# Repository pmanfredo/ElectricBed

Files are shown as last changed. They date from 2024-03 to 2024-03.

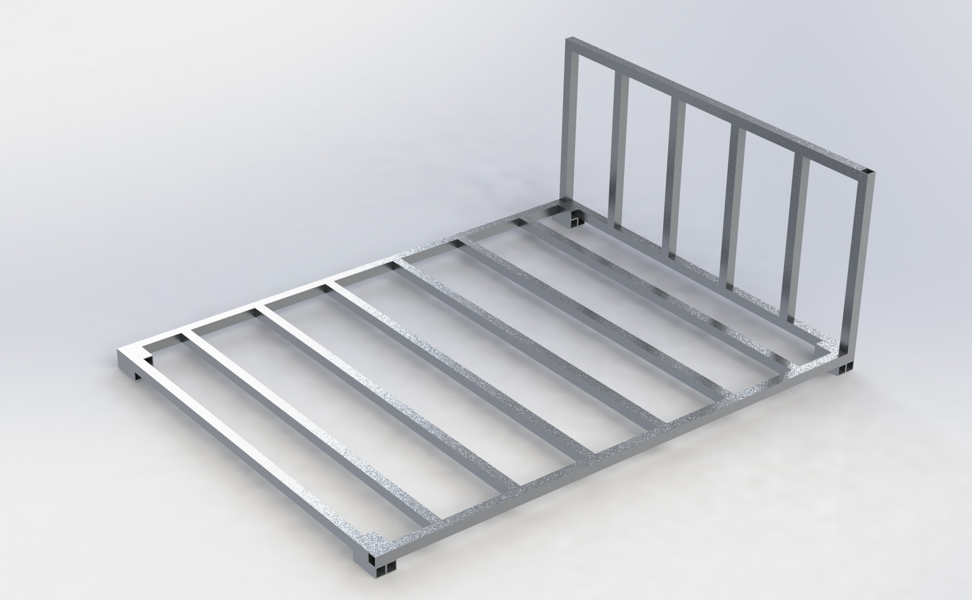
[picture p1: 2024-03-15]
Other Files/Renderings/electric bed render v1.JPG

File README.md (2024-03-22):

# ElectricBed: Motorized Queen-Sized Bed Project

Welcome to the `ElectricBed` project! This comprehensive guide is designed to assist you in creating a low-speed, electrically powered vehicle, uniquely constructed as a queen-sized bed that can carry two people. It's remotely controlled, featuring advanced functionalities such as telemetry feedback, dynamic control systems, and LED lighting, all managed by an Arduino Mega 2560.

**This project is an ongoing endeavor, with new features and enhancements being added and completed over time.**

## Overview

The ElectricBed project transforms the concept of mobility and rest into a single, innovative design. Equipped with dual Electronic Speed Controllers (ESCs), input from a FlySky FS-i6X transmitter, LED lighting effects, and a motion sensor for enhanced driving stability, this project invites hobbyists and developers to explore the fusion of comfort and technology.

### Key Features

- Dynamic speed and turn control for smooth maneuverability.
- Telemetry feedback for battery monitoring and RPM-based adjustments, ensuring safe and efficient operation.
- Customizable LED lighting for aesthetic appeal and visibility.
- Motion detection for improved stability and traction control, enhancing passenger comfort.
- Auxiliary controls via relays for headlights, parking lights, turn signals, horn, reverse light, and volume control.
- Comprehensive safety features such as an emergency stop mechanism and a 2-step kill switch.

### Required Hardware

- Arduino Mega 2560 for central control.
- Two Electronic Speed Controllers (ESCs) for motor management.
- FlySky FS-i6X remote control transmitter and receiver for remote operation.
- HiLetgo X9C104 Digital Potentiometer Module for volume control.
- Adafruit NeoPixel LED Strip for customizable lighting.
- MPU6050 Accelerometer and Gyro Sensor for motion detection and stability control.
- Relay module(s) for controlling auxiliary features like headlights, parking lights, turn signals, horn, and reverse light.
- Adequate power sources for the Arduino, ESCs, LEDs, and any other peripherals.

### Wiring Instructions

1. **ESC Connections**: Connect the ESCs to the Arduino's `Serial1` and `Serial2` ports (TX1/RX1 for ESC 1, TX2/RX2 for ESC 2) for motor control.
2. **iBus Receiver**: Connect to `Serial3` (TX3/RX3) on the Arduino to receive input from the FlySky transmitter.
3. **LED Strip**: Attach to pin `6` on the Arduino for lighting effects.
4. **MPU6050 Sensor**: Use the Arduino's I2C ports (SDA and SCL) for connection.
5. **Digital Potentiometer**: Connect the U/D, INC, and CS pins of the X9C104 to digital pins `10`, `11`, and `12` respectively on the Arduino.
7. **Power Connections**: Ensure all components are appropriately powered according to their specifications.

## Relay Wiring Instructions

The project utilizes a series of relays to control various components such as turn signals, headlights, horn, and more. Below are the detailed wiring instructions for each relay connected to the Arduino:

- **Relays**: The project uses relays for controlling different functionalities. Each relay is controlled by a specific digital pin on the Arduino Mega 2560.

### Relay Connections

- **Relay 1 (Headlights)**: Connect to digital pin 2.
- **Relay 2 (Parking Lights)**: Connect to digital pin 3.
- **Relay 3 (Horn)**: Connect to digital pin 4.
- **Relay 4 (Turn Signals - Left)**: Connect to digital pin 5.
- **Relay 5 (Turn Signals - Right)**: Connect to digital pin 6.
- **Relay 6 (Reverse Light)**: Connect to digital pin 7.
- **Relay 7 (Volume Control/Mute for Sound System)**: Connect to digital pin 8.
- **Relay 8 (LED Scene Control)**: Connect to digital pin 9.

### Program Overview

The provided code orchestrates various functions:

- Initialization of serial ports, ESCs, iBus receiver, relays, LED strip, digital potentiometer, and I2C devices in the `setup()`.
- Continuous monitoring and processing of control inputs, telemetry data, safety checks, and volume adjustments in the `loop()`.
- Customizable control modes (RPM, Duty, Current) for varying operational preferences.
- Relay control for auxiliary functions and LED color customization for personalization and visibility.

### Volume Control Setup

- At startup, the digital potentiometer is reset to its minimum value to establish a reference point.
- Volume adjustments are made relative to this reference point, allowing for precise control over the audio output level.
- The current position of the digital potentiometer's wiper is tracked to facilitate efficient and accurate adjustments.

### Getting Started

1. Assemble the bed frame and attach the motors, ensuring all hardware is securely mounted.
2. Wire the components according to the instructions, taking care to correctly connect all electronic elements.
3. Upload the program to your Arduino Mega 2560.
4. Configure the FlySky transmitter to communicate with the receiver.
5. Conduct initial tests in a safe, controlled environment to ensure stability and operational safety.

### Customization and Safety

Customize acceleration rates, turn sensitivity, LED behavior, and more to enhance the driving experience and ensure passenger comfort. Prioritize safety by securely fastening all components and conducting thorough testing before use.

Enjoy building and operating your ElectricBed, a unique blend of technology, comfort, and mobility!

## Upcoming Features

We're continuously working to enhance the ElectricBed experience with innovative features and improvements. Here are some of the exciting updates you can look forward to as we get them completed:

### Sound System with Remote Volume Control

Enjoy an immersive audio experience with a fully integrated sound system. Future updates will include the ability to control the volume directly from your FlySky FS-i6X remote, allowing for seamless adjustments without the need to stop or reach for a separate controller. Whether you're looking to set the mood with some background music or amp up the energy with your favorite tracks, having control at your fingertips will enhance your ElectricBed experience.

### Electric Bed App for Monitoring and Security Enhancements

Stay connected with your ElectricBed through our upcoming dedicated app. This application will not only allow you to monitor key vehicle metrics in real-time, such as battery levels, speed, and system diagnostics, but it will also introduce new layers of security and convenience:

- **Remote Monitoring**: Check on your ElectricBed's status, ensuring it's always ready for your next adventure.
- **Security Alerts**: Receive instant notifications for unauthorized movements or tampering, offering peace of mind when you're away from your vehicle *when it is on*.
- **Future Updates**: The app will serve as a platform for rolling out future features and enhancements, keeping your ElectricBed at the cutting edge of technology.

Stay tuned for these updates and more as we continue to innovate and expand the capabilities of the ElectricBed project. 

**If you have any features you would like to see added, please make a pull request or add to our discussion!**

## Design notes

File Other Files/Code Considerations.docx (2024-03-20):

# ### 1. **Error Handling and Safety Features:**

~~- **Fail-Safe~~ ~~Mechanism:*~~~~* Ensure there's a fail-safe mechanism in case the signal from the~~ ~~FlySky~~ ~~remote is lost. This could involve setting the motors to a neutral or stopped state if no signal is received for a predefined period.~~

- **Signal Validation:** Implement checks to ensure that the signals received from the remote are within expected ranges before acting on them, to prevent erratic behavior due to signal interference or corruption.

# ### 2. **Refinement in Speed and Turn Calculations:**

~~- **Smooth~~ ~~Acceleration:*~~~~* Consider implementing a smoother acceleration curve to avoid sudden starts and stops, which could be achieved through software by gradually adjusting the speed values towards the target speed.~~

- **Advanced Turning Logic:** For more intuitive control, especially at varying speeds, you might want to adjust the turning logic based on the current speed. At high speeds, smaller adjustments to turning might be preferable to maintain stability.

# ### 3. **Telemetry and Feedback:**

~~- **Use of Telemetry~~ ~~Data:*~~~~* If your ESCs support telemetry, you can use this data for battery monitoring, RPM feedback, and possibly for implementing features like traction control or even a simple form of stability control by adjusting power to the motors based on their actual RPM.~~

- **Feedback to Operator:** Consider sending critical telemetry data back to the operator through the remote's display if supported, or via an auxiliary display attached to the remote. This could include battery level, signal strength, or error codes.

# ### 4. **Motor Control Enhancements:**

~~- **Differential~~ ~~Steering:*~~~~* If your vehicle's design allows, differential steering (adjusting the speed of each side's motors independently for turning) can offer more precise control, especially at lower speeds or for in-place turns.~~

~~- **Dynamic ESC~~ ~~Configuration:*~~~~* Some ESCs allow dynamic configuration of parameters such as acceleration curves, braking strength, and reverse functionality. Adjusting these settings programmatically based on the vehicle's speed, direction, or operator input can enhance driving characteristics.~~

# ### 5. **Software Architecture:**

~~- **~~~~Modularity:*~~~~* Keep your code modular by separating functionality (e.g., motor control, signal processing, telemetry) into different functions or classes. This approach improves readability and makes it easier to maintain and extend your code.~~

~~- **Real-Time~~ ~~Considerations:*~~~~* Given the real-time nature of remote control, ensure your loop runs efficiently to minimize latency. Avoid or minimize the use of `~~~~delay(~~~~)`, and consider non-blocking alternatives for any task that might introduce lag.~~

# ### 6. **Debugging and Configuration Tools:**

- **Serial Debugging:** Utilize serial output for debugging purposes, providing insights into the system's state, received commands, and any errors or warnings.

- **Configuration Parameters:** Implement a mechanism (via remote control inputs, serial commands, or even a small set of buttons and an LCD on the vehicle) to adjust configuration parameters on the fly, such as maximum speed, sensitivity to control inputs, and fail-safe settings.

# ### 7. **Power Management:**

- **Power Supply Monitoring:** Continuously monitor the power supply to ensure the motors and ESCs are not drawing too much current, which could lead to voltage drops and potential brown-out conditions for the control electronics.

- **Efficient Power Use:** Optimize the power usage based on the telemetry data and the vehicle's operational state. For example, reducing power to the motors when the battery voltage drops below a certain threshold to extend run time.

# ### 8. **Documentation and Comments:**

- **Code Comments:** Ensure your code is well-commented, explaining the purpose of functions and the logic behind critical sections of your code. This practice is invaluable for maintenance and future modifications.

- **External Documentation:** Create external documentation for your project, including schematics, a wiring diagram, and a user manual. This is especially helpful if the project is complex or intended for use by others.

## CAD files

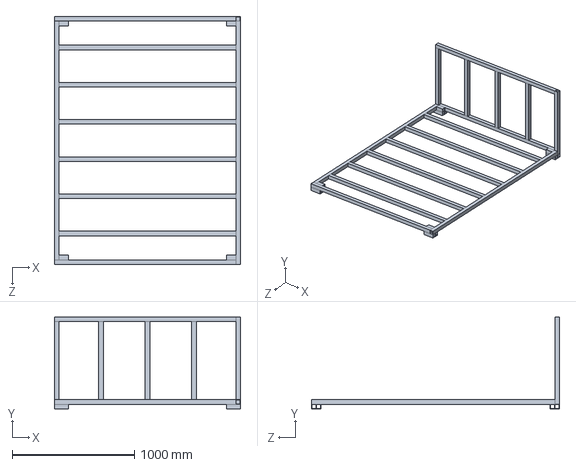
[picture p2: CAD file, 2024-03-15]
Other Files/Electric Bed Assembly.SLDASM
1524.0 x 752.5 x 2032.0 mm

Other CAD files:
Other Files/Bed Frame.SLDPRT
Other Files/Electric Bed Drawing.SLDDRW

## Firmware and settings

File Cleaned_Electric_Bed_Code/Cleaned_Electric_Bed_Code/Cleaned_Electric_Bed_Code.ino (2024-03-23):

#include <IBusBM.h>
#include <VescUart.h>
#include <Adafruit_NeoPixel.h>
#include "I2Cdev.h"
#include "MPU6050.h"
#if I2CDEV_IMPLEMENTATION == I2CDEV_ARDUINO_WIRE
    #include "Wire.h"
#endif

VescUart UART1; // VescUart object for commanding the ESC's
VescUart UART2; // VescUart object for commanding the ESC's
IBusBM IBus;    // IBus object for receiving signals from transmitter/receiver

unsigned long lastSignalTime = 0;         // Tracks the last time the signal was confirmed
const unsigned long signalTimeout = 1000; // Signal timeout in milliseconds
uint16_t lastCntRec = 0;                  // Last received count for detecting signal loss

// Control variables
int currentSpeed = 0, targetSpeed = 0, currentTurn = 0, targetTurn = 0;
int accelRate = 50, turnRate = 100; // Rate of change for speed and turn

// Telemetry variables
float batteryVoltage1 = 0.0, batteryVoltage2 = 0.0;
const float voltageWarningThreshold = 33.0;  // Threshold for 10S battery

bool movementEnabled = true; // Global variable to track movement enable state
bool reverse = false;

enum ControlMode { MODE_RPM, MODE_DUTY, MODE_CURRENT };
ControlMode controlMode = MODE_RPM; // Choose control mode: MODE_RPM, MODE_DUTY, or MODE_CURRENT

// ibus Channel Assignments
#define RJoyX 0
#define RJoyY 1
#define LJoyY 2
#define LJoyX 3
#define LPot 4
#define RPot 5
#define SWA 6
#define SWB 7
#define SWC 8
#define SWD 9
#define ON 1000
#define OFF 2000
#define MID 1500

bool startup = true;
bool dangerousTemp = false;
bool dangerousCurrent = false;
bool dangerousDuty = false;

// Temperature thresholds (degrees Celsius)
const float MOSFET_SAFE_TEMP = 80.0; // Maximum safe temperature for the ESC's MOSFETs
const float MOTOR_SAFE_TEMP = 80.0;  // Maximum safe temperature for the motor

// Current limits (Amps)
const float MOTOR_CURRENT_LIMIT = 50.0; // Maximum safe current for the motor

// Duty cycle limit (percentage)
const float DUTY_CYCLE_LIMIT = 95.0; // Maximum safe duty cycle percentage

// Define relay channels to Arduino pin numbers
const int relay1 = 2;
const int relay2 = 3;
const int relay3 = 4;
const int relay4 = 5;
const int relay5 = 6;
const int relay6 = 7;
const int relay7 = 8;
const int relay8 = 9;

// For tracking left joystick x-axis double-tap
unsigned long leftJoystickFirstHitTime = 0;
const unsigned long doubleTapMaxInterval = 500; // Max interval in ms for double-tap detection
bool leftJoystickInRangeLastTime = false;
int leftJoystickHitCount = 0;

const unsigned long hornDuration = 500; // Duration of the horn beep in milliseconds

// Define the pin that the LED strip is connected to
#define LED_PIN 6

// Define the number of LEDs in the strip
#define LED_COUNT 600

unsigned long previousMillis = 0; // will store last time LED was updated
const long interval = 0; // interval at which to blink (milliseconds)
unsigned int i = 0;

// Create an Adafruit_NeoPixel object
Adafruit_NeoPixel strip(LED_COUNT, LED_PIN, NEO_GRB + NEO_KHZ800);

MPU6050 accelgyro;
const int quickTurnThreshold = 100; // Example threshold, adjust based on testing

// Digipot control pins
const int pinUD = 10; // Up/Down pin
const int pinINC = 11; // Increment pin
const int pinCS = 12; // Chip Select pin

int currentWiperPosition = 0; // Current wiper position, starting at 0 (minimum)

// Setup function initializes the serial communication ports and prepares the system for operation.
void setup(){
    initializeSerial();
    setupESCs();
    IBus.begin(Serial3);
    waitForReceiver();
    //initializeRelays();
    initializeLEDStrip();
    //initializeI2CDevices();
}

// Main loop function checks for signal loss and processes control inputs if signal is present.
void loop(){
  //serialInput();
  //printChannelValues();
  if (IBus.cnt_rec != lastCntRec)
  {                            // Checks if new iBus messages have been received since the last loop iteration.
    updateTelemetry();         // Updates telemetry data from the ESCs for features like battery monitoring.
    processControlInputs();    // Reads control inputs from the receiver and adjusts motor speeds accordingly.
    lastCntRec = IBus.cnt_rec; // Updates the last iBus message count for the next loop iteration.
    lastSignalTime = millis(); // Updates the last signal time to the current time.
  }
  //delay(2000);
}

// Function to initialize the ESCs (Electronic Speed Controllers) by setting their respective serial ports.
void setupESCs(){
  Serial.println("Initializing ESCs..."); // Log message indicating the start of ESC initialization
  UART1.setSerialPort(&Serial1);          // Assigns Serial1 to UART1, linking the ESC to the first serial port
  UART2.setSerialPort(&Serial2);          // Assigns Serial2 to UART2, linking the second ESC to another serial port
  Serial.println("ESCs Initialized.");    // Log message indicating the ESCs have been successfully initialized
}

// Function to wait for the receiver to start sending data. This ensures the program doesn't proceed without a signal.
void waitForReceiver(){
  Serial.println("Waiting for receiver..."); // Log message indicating the program is waiting for receiver data
  while (IBus.cnt_rec == 0)
    delay(100);                          // Waits in a loop, delaying 100ms at a time until data is received from the receiver
  lastCntRec = IBus.cnt_rec;             // Stores the count of received messages for later comparison
  lastSignalTime = millis();             // Stores the current time as the last time a signal was received
  Serial.println("Receiver connected."); // Log message indicating a connection to the receiver has been established
}

void initializeSerial() {
    Serial.begin(9600);
    Serial1.begin(115200);
    Serial2.begin(115200);
    Serial3.begin(115200);
}

void initializeRelays() {
    const int relays[] = {relay1, relay2, relay3, relay4, relay5, relay6, relay7, relay8};
    for (int relay : relays) {
        pinMode(relay, OUTPUT);
        digitalWrite(relay, HIGH); // Assuming HIGH means OFF
    }
}

void initializeLEDStrip() {
    strip.begin();
    strip.show(); // Initialize all pixels to 'off'
}

void initializeI2CDevices() {
    Wire.begin();
    Serial.println("Initializing I2C devices...");
    accelgyro.initialize();
    Serial.println(accelgyro.testConnection() ? "MPU6050 connection successful" : "MPU6050 connection failed");
}

void setupDigipot() {
  pinMode(pinUD, OUTPUT);
  pinMode(pinINC, OUTPUT);
  pinMode(pinCS, OUTPUT);

  digitalWrite(pinCS, HIGH); // Deselect the device by default

  resetDigipotToMinimum();
}

void resetDigipotToMinimum() {
    // Select the digipot
    digitalWrite(pinCS, LOW);

    // Set to decrease wiper position
    digitalWrite(pinUD, LOW);
    for (int i = 0; i < 100; i++) { // Assuming 100 steps for the digipot
        // Pulse the INC pin
        digitalWrite(pinINC, HIGH);
        delay(1); // Short delay for the signal to register
        digitalWrite(pinINC, LOW);
        delay(1);
    }

    // Deselect the digipot
    digitalWrite(pinCS, HIGH);
}

void processControlInputs() {
  readInputs();
  checkTurnSignals();
  checkHornControl();
  checkHeadlights();
  checkHazardLights();
  controlVolumeAndMute();
  controlLEDScenes();

  // Applies smooth adjustments to speed and turn to avoid abrupt changes
  smoothAdjustments();
  
  //Turn system OFF or set current to 0 if input is 1000
  if (targetSpeed <= 1000) {
      UART1.setCurrent(0);
      UART1.setCurrent(0,101);
      UART2.setCurrent(0);
      UART2.setCurrent(0,101);
      //Serial.println("System turned off - Current set to 0.");
      currentSpeed = 1000;
      return;
  }

  // Depending on the control mode, map targetSpeed to the respective range and apply control
  switch (controlMode) {
      case MODE_RPM:
          // Map targetSpeed (1001-2000) to RPM range (0-7000), considering 1000 as OFF
          int rpmValue = map(currentSpeed, 1001, 2000, 1000, 7000);

          if (dangerousTemp || dangerousCurrent || dangerousDuty){
            rpmValue = rpmValue / 2;
          }

          if(reverse){
            rpmValue = -rpmValue;
          }
          applyControlRPM(rpmValue);
          break;
      case MODE_DUTY:
          // Map targetSpeed (1001-2000) to duty cycle range (0-80%)
          float dutyCycle = map(targetSpeed, 1001, 2000, 0, 80);

          if (dangerousTemp || dangerousCurrent || dangerousDuty){
            dutyCycle = dutyCycle / 2;
          }

          if(reverse){
            dutyCycle = -dutyCycle;
          }
          applyControlDuty(dutyCycle);
          break;
      case MODE_CURRENT:
          // Map targetSpeed (1001-2000) to current range (0-40A)
          float current = map(targetSpeed, 1001, 2000, 0, 40);

          if (dangerousTemp || dangerousCurrent || dangerousDuty){
            current = current / 2;
          }

          if(reverse){
            current = -current;
          }
          applyControlCurrent(current);
          break;
  }
}

void checkTurnSignals(){
  // Handling Left Joystick X-Axis for Turn Signals
  int leftJoystickX = IBus.readChannel(LJoyX);
  unsigned long currentMillis = millis();

  // Reset hit count if interval exceeds max double-tap interval
  if (currentMillis - leftJoystickFirstHitTime > doubleTapMaxInterval && leftJoystickHitCount > 0) {
      leftJoystickHitCount = 0;
  }

  if ((leftJoystickX >= 1000 && leftJoystickX <= 1100) || (leftJoystickX >= 1900 && leftJoystickX <= 2000)) {
    if (!leftJoystickInRangeLastTime) {
        leftJoystickInRangeLastTime = true;
        leftJoystickHitCount++;
        leftJoystickFirstHitTime = currentMillis;

        // If first hit, deactivate both relays
        if (leftJoystickHitCount == 1) {
            turnOffRelay(relay1); // Turn off Relay 2
            turnOffRelay(relay2); // Turn off Relay 3
        }

        // If second hit and within interval, activate the appropriate relay and ensure the other is off
        if (leftJoystickHitCount == 2) {
            if (leftJoystickX >= 1000 && leftJoystickX <= 1100) {
                turnOffRelay(relay2); // Ensure Relay 3 is off
                turnOnRelay(relay1); // Turn on Relay 2 for left turn signal
            } else if (leftJoystickX >= 1900 && leftJoystickX <= 2000) {
                turnOffRelay(relay1); // Ensure Relay 2 is off
                turnOnRelay(relay2); // Turn on Relay 3 for right turn signal
            }
            leftJoystickHitCount = 0; // Reset count after activation
        }
    }
  } else {
      leftJoystickInRangeLastTime = false;
    }

}

void checkHornControl() {
    static bool hornBeeped = false; // Tracks if a short beep was already made
    static unsigned long hornStartTime = 0; // Tracks when the horn beep started
    int rightJoystickY = IBus.readChannel(RJoyY); // Reading the Y-axis of the right joystick

    if (rightJoystickY >= 1900 && rightJoystickY <= 2000) {
        turnOnRelay(relay3); // Continuous horn - Joystick pushed upwards
        hornBeeped = false; // Reset beeped flag for next operation
    } else if (rightJoystickY >= 1000 && rightJoystickY <= 1100 && !hornBeeped) {
        // Short beep - Joystick pushed downwards
        if (hornStartTime == 0) { // If the beep hasn't started yet
            turnOnRelay(relay3); // Turn on relay4 for the horn
            hornStartTime = millis(); // Mark the start time of the beep
        }
        if (millis() - hornStartTime > hornDuration) { // If the beep duration has passed
            turnOffRelay(relay3); // Turn off relay4 after the short beep duration
            hornBeeped = true; // Set flag to true to avoid repeating the beep
            hornStartTime = 0; // Reset start time for next beep
        }
    } else if (rightJoystickY > 1100 && rightJoystickY < 1900) {
        // Resets the horn beeped flag when the joystick is neither fully up nor down
        hornBeeped = false;
        hornStartTime = 0; // Reset start time for next beep
        turnOffRelay(relay3); // Ensure the relay is off when not in the beep or continuous horn zones
    }
}

void checkHeadlights() {
    int swcValue = IBus.readChannel(SWC); // Reading the value of the SWC switch

    if (swcValue == OFF) {
        // If SWC is 1000, both relay5 and relay6 are off
        turnOffRelay(relay4);
        turnOffRelay(relay5);
    } else if (swcValue == MID) {
        // If SWC is 1500, relay5 is on and relay6 is off
        turnOnRelay(relay4);
        turnOffRelay(relay5);
    } else if (swcValue == ON) {
        // If SWC is 2000, both relay5 and relay6 are on
        turnOnRelay(relay4);
        turnOnRelay(relay5);
    }
}

void checkHazardLights() {
    int swdValue = IBus.readChannel(SWD); // Reading the value of the SWD switch

    if (swdValue == OFF) {
        // If SWD is 1000, relay7 is off
        turnOffRelay(relay6);
    } else if (swdValue == OFF) {
        // If SWD is 2000, relay7 is on
        turnOnRelay(relay6);
    }
}

// Reads inputs from the remote control receiver and maps them to target speed and turn values.
void readInputs(){
    // Step 1: Ensure all switches are OFF before proceeding
  while (startup) {
    int swaState = IBus.readChannel(SWA);
    int swbState = IBus.readChannel(SWB);
    int swcState = IBus.readChannel(SWC);
    int swdState = IBus.readChannel(SWD);

    if (swaState == OFF && swbState == OFF && swcState == OFF && swdState == OFF) {
      startup = false;
      break; // Exit the loop if all switches are OFF
    }

    Serial.println("Ensure all switches are OFF to proceed.");
    delay(500); // Delay to prevent flooding the serial output
  }

  // Step 2: Proceed with kill switch logic, incorporating the SWB safety feature
  static bool swbSafetyCheckPassed = false; // Static variable to track if the SWB safety check has passed

  while (true)
  {
    int killState = IBus.readChannel(SWA);
    
    // Reset SWB safety check if kill switch is turned OFF
    if (killState == OFF) {
      swbSafetyCheckPassed = false;
      stopMotors();
      movementEnabled = false;
      currentSpeed = 1000;
      Serial.println("Movement Disabled. Kill switch is OFF. SWB safety check reset.");
    }

    // Conduct SWB safety check only if it hasn't been passed yet
    if (!swbSafetyCheckPassed) {
      int swbState = IBus.readChannel(SWB);
      if (killState == ON && swbState == ON) {
        swbSafetyCheckPassed = true;
        Serial.println("SWB safety check passed. System starting in forward.");
      } else {
        Serial.println("Waiting for SWB to be turned ON for safety check.");
        delay(500); // Delay to prevent flooding the serial output
        continue; // Remain in loop until SWB is ON and kill switch is ON
      }
    }

    // Exit loop and allow system to proceed if killState is ON and SWB safety check has been passed
    if (killState == ON && swbSafetyCheckPassed) {
      if (!movementEnabled) {
        movementEnabled = true;
        Serial.println("Movement Enabled. Kill switch is ON.");
      }
      break; // Exit the loop if conditions are met
    }
    
    delay(100); // Brief delay to reduce CPU load during loop
  }

  targetSpeed = IBus.readChannel(LJoyY); // Reads the speed input from Left Joystick Y Axis of the receiver

  int reverseValue = IBus.readChannel(SWB);

  if (reverseValue == OFF && targetSpeed == 1000)
  {
    // If true, maps the speed value for reverse direction
    reverse = true;
  }

  if (reverseValue == ON && targetSpeed == 1000){
    reverse = false;
  }

  // Reads the turn input from Right Joystick X Axis and maps it to a target turn value
  targetTurn = (int)(IBus.readChannel(RJoyX) -1500); // 1000 (left) to 2000 (right), 1500 is neutral, turn -500 to 500
}

// Applies smooth adjustments to the current speed and turn values to reach the target values without abrupt changes.
void smoothAdjustments(){
  checkAndAdjustForQuickTurns();

  // Adjusts the current speed towards the target speed at a controlled rate (accelRate)
  if (currentSpeed < targetSpeed)
    currentSpeed += min(accelRate, targetSpeed - currentSpeed); // Increases speed if below target
  else if (currentSpeed > targetSpeed)
    currentSpeed -= min(accelRate, currentSpeed - targetSpeed); // Decreases speed if above target

  // Adjusts the current turn rate towards the target turn rate at a controlled rate (turnRate)
  if (currentTurn < targetTurn)
    currentTurn += min(turnRate, targetTurn - currentTurn); // Increases turn rate if below target
  else if (currentTurn > targetTurn)
    currentTurn -= min(turnRate, currentTurn - targetTurn); // Decreases turn rate if above target

  //Serial.println(currentSpeed);
}

void checkAndAdjustForQuickTurns() {
    int16_t ax, ay, az;
    int16_t gx, gy, gz;
    accelgyro.getMotion6(&ax, &ay, &az, &gx, &gy, &gz);

    // Assuming gz (rotation around the Z-axis) is your turning axis
    // The sensitivity scale factor for the gyroscope is 131 LSB/degrees/sec
    // according to the MPU-6050 datasheet when using the default sensitivity setting.
    float turnRate = gz / 131.0;

    if (abs(turnRate) > quickTurnThreshold) {
        // Quick turn detected, reduce target speed
        Serial.println("Quick turn detected, reducing speed.");
        targetSpeed = targetSpeed / 2; // Example reduction, adjust as needed
    }
}

void applyControlRPM(int rpm) {
  //Serial.print("Applying RPM");
  // Calculate left and right motor RPM based on target turn and speed adjustments
  int leftRPM = constrain(rpm + (2 * currentTurn), -7000, 7000);
  int rightRPM = constrain(rpm - (2 * currentTurn), -7000, 7000);
  UART1.setRPM(leftRPM);
  UART2.setRPM(leftRPM);
  UART1.setRPM(rightRPM,101);
  UART2.setRPM(rightRPM,101);
  // Serial.print("Left RPM set to: "); Serial.println(leftRPM);
  // Serial.print("Right RPM set to: "); Serial.println(rightRPM);
  // delay(500);
}

void applyControlDuty(float dutyCycle) {
  // Apply duty cycle control to motors
  int leftDutyCycle = constrain(dutyCycle + (0.05 * currentTurn), 0, 80);
  int rightDutyCycle = constrain(dutyCycle - (0.05 * currentTurn), 0, 80);
  UART1.setDuty(leftDutyCycle);

  UART2.setDuty(leftDutyCycle);
  UART1.setDuty(rightDutyCycle, 101);
  UART2.setDuty(rightDutyCycle, 101);
  Serial.print("Left Duty Cycle set to: "); Serial.println(leftDutyCycle);
}

void applyControlCurrent(float current) {
  // Apply current control to motors, adjustments for turning not demonstrated
  int leftCurrent = constrain(current + (0.025 * currentTurn), 0, 40);
  int rightCurrent = constrain(current - (0.025 * currentTurn), 0, 40);
  UART1.setCurrent(leftCurrent);
  UART2.setCurrent(leftCurrent);
  UART1.setCurrent(rightCurrent,101);
  UART2.setCurrent(rightCurrent,101);
  Serial.print("Current set to: "); Serial.println(current);
}

// Updates telemetry data from the ESCs, including battery voltage and motor RPM, and checks for low battery voltage.
void updateTelemetry(){
  // Retrieve and store telemetry data for each ESC
  if (UART1.getVescValues())
  {
    batteryVoltage1 = UART1.data.inpVoltage; // Store battery voltage from ESC 1

    // Serial.print("Battery Voltage: ");
    // Serial.println(batteryVoltage1);
  }
  if (UART2.getVescValues())
  {
    batteryVoltage2 = UART2.data.inpVoltage; // Store battery voltage from ESC 2

    // Serial.print("Battery Voltage: ");
    // Serial.println(batteryVoltage2);
  }

  // Check if either battery voltage is below the threshold and warn if so
  if (batteryVoltage1 < voltageWarningThreshold || batteryVoltage2 < voltageWarningThreshold)
  {
    //Serial.println("Warning: Low Battery Voltage!"); // Print a low battery warning
  }

  checkSystemHealth();
}

void checkSystemHealth() {
  if (UART1.data.tempMosfet > MOSFET_SAFE_TEMP || UART1.data.tempMotor > MOTOR_SAFE_TEMP || UART2.data.tempMosfet > MOSFET_SAFE_TEMP || UART2.data.tempMotor > MOTOR_SAFE_TEMP) {
    Serial.println("High temperature detected. Reducing performance.");
    dangerousTemp = true;
  } else {
    dangerousTemp  = false;
  }

  if (UART1.data.avgMotorCurrent > MOTOR_CURRENT_LIMIT || UART2.data.avgMotorCurrent > MOTOR_CURRENT_LIMIT) {
    Serial.println("High motor current detected. Adjusting control.");
    // Adjust control logic here
    dangerousCurrent = true;
  } else {
    dangerousCurrent  = false;
  }

  if (UART1.data.dutyCycleNow > DUTY_CYCLE_LIMIT || UART2.data.dutyCycleNow > DUTY_CYCLE_LIMIT) {
    Serial.println("High duty cycle detected. Adjusting control.");
    // Reduce demanded RPM or switch control mode
    dangerousDuty = true;
  } else {
    dangerousDuty  = false;
  }
}

// Stops the motors by setting their speed values to neutral, used in cases of signal loss or as part of a shutdown procedure.
void stopMotors(){
  UART1.setBrakeCurrent(5);
  UART1.setBrakeCurrent(5,101);
  UART2.setBrakeCurrent(5);
  UART2.setBrakeCurrent(5,101);
  Serial.println("Braking!");
}

void serialInput(){
  if (Serial.available() > 0) {
    // Read the incoming data as a string until newline is encountered
    String dataString = Serial.readStringUntil('\n');
    // Convert the string to an integer
    int incomingInt = dataString.toInt();
    if (incomingInt == -1) {
      currentSpeed = 0;
      targetSpeed = 0;
      UART1.setBrakeCurrent(5);
      UART1.setCurrent(0,0);
      UART1.setCurrent(0,101);
      Serial.println("Braking!");
    }else{
      targetSpeed = incomingInt;
      Serial.print("Received targetSpeed: ");
      Serial.println(targetSpeed);
    }


  }
}

void turnOnRelay(int relayPin) {
  digitalWrite(relayPin, LOW); // Turn relay on
}

void turnOffRelay(int relayPin) {
  digitalWrite(relayPin, HIGH); // Turn relay off
}

void setPixelColor(int pixel, uint8_t red, uint8_t green, uint8_t blue) {
  strip.setPixelColor(pixel, strip.Color(red, green, blue));
  strip.show();
}

void fillStrip(uint8_t red, uint8_t green, uint8_t blue) {
  for(int i = 0; i < LED_COUNT; i++) {
    strip.setPixelColor(i, strip.Color(red, green, blue));
  }
  strip.show();
}
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

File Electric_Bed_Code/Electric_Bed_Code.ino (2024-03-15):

#include <IBusBM.h>
#include <VescUart.h>

VescUart UART1; // VescUart object for commanding the ESC's
VescUart UART2; // VescUart object for commanding the ESC's

IBusBM IBus; // IBus object for receiving signals from transmitter/receiver

unsigned long lastSignalTime = 0; // Tracks the last time the signal was confirmed
unsigned long signalTimeout = 1000; // Signal timeout in milliseconds (1 second)
uint16_t lastCntRec = 0; // Last received count for detecting signal loss
int savespd=0, saveturn=0;

// Global variables for smooth acceleration
int currentSpeed = 127; // Assume starting at neutral
int targetSpeed = 127; // Target speed, initialized to neutral
int accelRate = 5; // Rate of acceleration towards target speed

// Advanced Turning Logic
int currentTurn = 0; // Current turn rate
int targetTurn = 0; // Target turn rate
int turnRate = 5; // Rate of turning towards target turn

// Global telemetry data variables
float batteryVoltage1 = 0.0;
float batteryVoltage2 = 0.0;
int32_t motorRPM1 = 0;
int32_t motorRPM2 = 0;

// Thresholds for functionality
// Adjust the voltage warning threshold for a 10S battery
const float voltageWarningThreshold = 3.3 * 10; // 33V for a 10S battery
const int32_t rpmDifferenceThreshold = 1000; // Example threshold for RPM difference

// Add variables for dynamic adjustment
int speedAdjustment = 0; // This will be used to adjust the speed difference between the two sets of motors


void setup() {
  /** Setup Serial port to enter commands */
  Serial.begin(9600);

  Serial1.begin(115200);
  Serial2.begin(115200);
  Serial3.begin(115200);

  Serial.println("Wait for ESC 1");
  while (!Serial1) {;}
  UART1.setSerialPort(&Serial1);

  Serial.println("Wait for ESC 2");
  while (!Serial2) {;}
  UART2.setSerialPort(&Serial2);

  IBus.begin(Serial3);
  Serial.println("Wait for receiver");
  while (IBus.cnt_rec==0) delay(100);

  lastCntRec = IBus.cnt_rec; // Initialize lastCntRec with the first received count
  lastSignalTime = millis(); // Record the time when the signal was last confirmed

  Serial.println("Init done");
}

void loop() {
  // Check for signal loss
  if (IBus.cnt_rec == lastCntRec) {
    // If the count hasn't changed, check the timeout
    if (millis() - lastSignalTime > signalTimeout) {
      // Signal is considered lost, stop motors
      stopMotors(); // Implement this function to stop motors safely
      return; // Skip further processing
    }
  } else {
    // Signal is present, update the last confirmed time and count
    lastCntRec = IBus.cnt_rec;
    lastSignalTime = millis();
    updateTelemetry(); // Update telemetry data
    adjustForTractionAndStability(); // Make adjustments based on telemetry
    processControl(); // Implement this function to handle normal control processing
  }
}

void processControl() {
  // Read the target speed and direction from channels
  targetSpeed = IBus.readChannel(2); // Speed control channel
  if (IBus.readChannel(5) > 1500) {
    // Reverse: Map 1050-2000 to 127-0
    targetSpeed = map(targetSpeed, 1050, 2000, 127, 0);
  } else {
    // Forward: Map 1050-2000 to 127-255
    targetSpeed = map(targetSpeed, 1050, 2000, 127, 255);
  }

  // Smoothly adjust current speed towards target speed
  if (currentSpeed < targetSpeed) {
    currentSpeed += min(accelRate, targetSpeed - currentSpeed);
  } else if (currentSpeed > targetSpeed) {
    currentSpeed -= min(accelRate, currentSpeed - targetSpeed);
  }

  // Read and adjust turn rate based on current speed
  targetTurn = (((int)IBus.readChannel(0) - 1500) * 4) / 10;
  // Adjust turn sensitivity based on speed
  if (abs(currentSpeed - 127) > 60) { // If speed is significantly above neutral
    targetTurn = targetTurn / 2; // Reduce turning sensitivity at higher speeds
  }

  // Smoothly adjust current turn towards target turn
  if (currentTurn < targetTurn) {
    currentTurn += min(turnRate, targetTurn - currentTurn);
  } else if (currentTurn > targetTurn) {
    currentTurn -= min(turnRate, currentTurn - targetTurn);
  }

  // Apply combined speed and turn adjustments
  speedturn(currentSpeed, currentTurn);

  if (savespd != currentSpeed || saveturn != currentTurn) {
    Serial.print("speed="); Serial.print(currentSpeed);
    Serial.print(" turn="); Serial.println(currentTurn);
    savespd = currentSpeed;
    saveturn = currentTurn;
  }
}

void speedturn(int speed, int angle) {
  // Incorporate speedAdjustment to align motor speeds for straight driving
  int leftSpeed = constrain(speed + angle - speedAdjustment, 0, 255);
  int rightSpeed = constrain(speed - angle + speedAdjustment, 0, 255);

  UART1.nunchuck.valueY = leftSpeed;
  UART2.nunchuck.valueY = rightSpeed;

  UART1.setNunchuckValues();
  UART2.setNunchuckValues();
}


void OLDgetTelemetry1() {
  if (UART1.getVescValues()) {
    Serial.println(UART1.data.rpm);
    Serial.println(UART1.data.inpVoltage);
    Serial.println(UART1.data.ampHours);
    Serial.println(UART1.data.tachometerAbs);
  }
}

void OLDgetTelemetry2() {
  if (UART2.getVescValues()) {
    Serial.println(UART2.data.rpm);
    Serial.println(UART2.data.inpVoltage);
    Serial.println(UART2.data.ampHours);
    Serial.println(UART2.data.tachometerAbs);
  }
}

void stopMotors() {
  // Set motors to neutral state
  UART1.nunchuck.valueY = 127;
  UART2.nunchuck.valueY = 127;
  UART1.setNunchuckValues();
  UART2.setNunchuckValues();
  Serial.println("Signal lost, stopping motors.");
}

void updateTelemetry() {
  if (UART1.getVescValues()) {
    batteryVoltage1 = UART1.data.inpVoltage;
    motorRPM1 = UART1.data.rpm;
  }
  if (UART2.getVescValues()) {
    batteryVoltage2 = UART2.data.inpVoltage;
    motorRPM2 = UART2.data.rpm;
  }
  
  // Battery monitoring
  if ((batteryVoltage1 / 10) < voltageWarningThreshold || (batteryVoltage2 / 10) < voltageWarningThreshold) { // Adjusting for 10S battery
    Serial.println("Warning: Low Battery Voltage!");
  }
  
  // No additional logic here for RPM adjustment, we'll handle it directly in the control logic
}

void adjustMotorPowerForStraightDrive() {
  int rpmDifference = motorRPM1 - motorRPM2;

  // If we're not trying to turn (based on a minimal turn input), adjust for straight drive
  if (abs(targetTurn) < 10) { // Assuming a small threshold indicates intention to drive straight
    if (abs(rpmDifference) > rpmDifferenceThreshold) {
      speedAdjustment = rpmDifference / 100; // Calculate adjustment, tune divisor as needed for sensitivity
    } else {
      speedAdjustment = 0; // No significant difference, no adjustment needed
    }
  } else {
    // Clear adjustment during turns to allow for natural handling
    speedAdjustment = 0;
  }
  
  // Apply this adjustment in the speedturn function
}
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

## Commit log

2024-03-15 Adding Files
    [Bed Frame.SLDPRT, Electric Bed Assembly.SLDASM, Electric Bed Drawing.SLDDRW]
2024-03-15 Organized the File Structure
    [Bed Frame.SLDPRT, Electric Bed Assembly.SLDASM, Electric Bed Drawing.SLDDRW]
2024-03-16 Removed signal loss code, won't work for my hardware, updated adjust for straight drive
    [Cleaned_Electric_Bed_Code.ino]
2024-03-17 Worked on some logic, beginning ESC UART testing
2024-03-17 More minor updates to code, blew the Arduino, waiting on new one
    [Cleaned_Electric_Bed_Code.ino]
2024-03-20 Code logic needs to be fixed, temp code currently there for testing
    [Cleaned_Electric_Bed_Code.ino]
2024-03-20 Worked on movement logic, allowing to switch between rpm, duty, and current
2024-03-20 Added kill switch logic
2024-03-20 Added logic for all swtiches down and fixed some ';' issues and wrong var names
    [Cleaned_Electric_Bed_Code.ino]
2024-03-20 Added skeleton relay and LED strip logic
2024-03-20 Added swd logic for a relay
2024-03-21 Added hazard lights logic, also fixed some syntax and repeated code
    [Cleaned_Electric_Bed_Code.ino]
2024-03-21 Worked on led scenes code
2024-03-22 LED code updated, some logic updates with acceleration and braking, working on reverse next
    [Cleaned_Electric_Bed_Code.ino]
2024-03-22 Fixed reverse logic, changed constrain which could cause issues later with turns, we will see in testing
    [Cleaned_Electric_Bed_Code.ino]
2024-03-23 Added temp, current, and duty protections
